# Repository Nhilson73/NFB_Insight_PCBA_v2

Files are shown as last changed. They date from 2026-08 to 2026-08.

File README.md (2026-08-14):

# NFB Insight PCBA v2

PCBA **shield/carrier** para **Nebula Fermentation Insight®**, diseñada alrededor del factor de forma inmutable del **Arduino UNO Q**. El repositorio `Nhilson73/nebula_qshield_pcb` es únicamente donante de ingeniería/trazabilidad; no gobierna placement, routing ni topología de producción V2.

## Fuente primaria UNO Q

Toda decisión dependiente del Arduino UNO Q se contrasta primero contra repositorios oficiales Arduino en GitHub (`github.com/Arduino`, especialmente `arduino/docs-content`), luego `docs.arduino.cc` y finalmente datasheets oficiales. La jerarquía y snapshots revisados viven en `docs/SOURCE_OF_TRUTH.md`.

## Frontera del producto / compliance

NFB Insight PCBA v2 es un **shield/carrier del UNO Q**, no un rediseño de su radio. No añade transmisores, antena, matching ni amplificación RF. El **EU Compliance Design Gate** vive en `docs/EU_COMPLIANCE_GATE.md` / `compliance/eu_compliance_contract.json` y cubre EMC, RoHS 3, REACH, WEEE, RED/CE del producto integrado.

## Mecánica y placement — PR #16 / #17 / ECO PR #22 / #24

- UNO Q rotado; origen global `(0,0)`; USB-C hacia `-Y`.
- Envolvente UNO Q / Z0: `53.34 × 68.58 mm`.
- Altura total PCB fija `68.58 mm`; crecimiento solo `+X`.
- `Y=0` = FIELD I/O EDGE; cables hacia `-Y`.
- Gradiente: Z0 UNO Q → Z1 sensores → Z2 digital → Z3 potencia → Z4 actuadores.
- **Ancho final de placement: `242.34 mm`.**
- Z0 `0.00→53.34 mm`.
- Z1 `53.34→108.84 mm` = `55.50 mm`.
- Z2 `108.84→163.34 mm` = `54.50 mm`.
- Z3 `163.34→198.34 mm` = `35.00 mm`.
- Z4 `198.34→242.34 mm` = `44.00 mm`.
- 119 footprints de producción + `J_UNOQ` = 120 footprints.
- 60 nets materializadas desde PR19D; `5V_HMI` es la net ECO añadida después de PR19C.
- PR17 cerró courtyard overlaps y fallos físicos de placement.
- PR22 aplicó el ECO acotado de placement alrededor del `TPSM33625` en Z3.
- PR24 acercó `TP_LOAD_A_POS/NEG` al HX711 en Z2 sin alterar el resto del placement.

## Z1 sensores

- pH/A0 y DO/A5: 0–3 V acondicionados, ESD + `1 kΩ / 100 nF`.
- ORP/A1: divisor `10 kΩ / 20 kΩ`, máximo 3.0 V.
- TEMP/A2-D16: DS18B20 `TEMP_1WIRE`.
- CO₂: Honeywell `MPRLS0030PA00002A`, I²C `0x28`; `CO2_ADC` retirado.
- A4/pad13 = `PUMP_CURRENT_ADC`.

## Z2 digital / bajo ruido

- I²C: MPR `0x28` + DFR1103 `0x66`.
- HX711 3.3 V / 10 SPS en D2/D3.
- HMI: **Nextion Intelligent `NX8048P050-011C-Y`**, 5.0 in capacitiva con enclosure, 800×480; D0/D1 mediante `TXU0202DCUR`.
- Accesorios HMI seleccionados: `SDExtender` + `Nextion BOX Speaker`; `Foca Max` queda como herramienta de programación/servicio.
- HMI+speaker reserva **5 V / 1.5 A**. PR19D cerró el ECO con `5V_HMI` dedicado externo (RECOM `R-78K5.0-2.0L` + fusible 2 A); display/audio ya no cargan `5V_RAIL`.
- Watchdog `TPS3823-30DBVR`, WDI=D4.
- `J_LOADCELL`: Phoenix Contact **1757268 / MSTBA 2,5/4-G-5,08**.

## Z3 potencia

Fuentes: `hardware/power_architecture_contract.json`, `hardware/power_production_netlist.json`, `hardware/power_netclasses.json` y `bom/insight_power_production_bom.csv`.

- 12 V protegido → VIN del UNO Q.
- `5V_RAIL` y `3V3_RAIL` son locales del shield; no se unen a J_UNOQ.5/J_UNOQ.4.
- Protección `SMBJ15A-TR + TPS259470ARPWR`.
- Split `12V_HOST_VIN / 12V_LOGIC / 12V_ACT`.
- `F_ACT=045401.5MR`.
- 5 V `TPSM33625RDNR`; 3.3 V `TLV75533PDBVR`.
- Potencia del chiller externa.

## Z4 actuadores

- Bomba `DRV8242HQRHLRQ1`, D5/D6, IPROPI → A4.
- Solenoide `TPS1HC120CQDYCRQ1`, D7, ILIM ~0.5 A.
- Chiller `AQY212EHAX` + `2N7002`, **dry contact SELV ≤48 V / NO MAINS**.
- D10=`ACT_FAULT_N`; D9 DNP/Reserva.

## Hierarchy EDA — PR #14 / #15

`kicad/NFB_Insight_PCBA_v2.kicad_sch` es el root Z0–Z4. PR #15 materializó las hojas desde JSON/BOM de forma determinista y eliminó completamente la deuda ERC del PR #14.

KiCad **10.0.5** sobre el hierarchy completo:

- **0 Errors**
- **0 Warnings**
- **0 violations**

Los JSON/BOM siguen siendo autoridad; las hojas generadas no deben editarse manualmente para alterar conectividad.

## Routing readiness — PR #18

Fuente: `hardware/routing_contract.json`; narrativa: `docs/FASE5_PR18_ROUTING_READINESS.md`.

PR #18 **no añadió cobre**. Su función fue congelar las reglas antes de rutear:

- exactamente **59/59 nets** cubiertas una sola vez por 11 clases;
- mínimos de potencia heredados de PR #10 no pueden debilitarse;
- `In1.Cu` = **GND continuo; signal routing prohibido**;
- `In2.Cu` = distribución de potencia, sin analógica sensible;
- pH/ORP/DO, load-cell/HX711 y `PUMP_CURRENT_ADC` forman dominio sensible;
- `12V_ACT`, `PUMP_OUT1/2` y `CO2_SOL_POS` forman dominio dirty;
- separación contractual sensitive↔dirty ≥ `1.00 mm` en recorridos paralelos;
- `12V_ACT` y retornos high-current no atraviesan Z1/Z2;
- contactos de chiller permanecen aislados, SELV ≤48 V y sin tie a GND;
- `SW`, `CO2_ADC`, `TEMP_ADC`, `HUM_ADC`, `CO2_PWM`, `CO2_FLOW_PWM` y `RS485_IRQ_RSVD` están prohibidas como nets de producción.

El `TPSM33625` es un módulo integrado y no expone una net SW externa. Su entrada/salida/feedback deben permanecer compactos en Z3.

## Tooling KiCad — PR #25

Las reglas operativas para agentes y automatización KiCad viven en `docs/KICAD_TOOLING_NOTES.md`, `docs/ROUTING_KNOWLEDGE_BASE.md` y `hardware/kicad_tooling_contract.json`.

Principios relevantes:

- `.kicad_pcb + .kicad_pro + .kicad_dru` se tratan como triplete canónico;
- KiCad 10.0.5 DRC es la autoridad física final;
- no se relajan clearances globales para hacer pasar routing;
- pads compuestos se modelan como geometría múltiple pero un endpoint lógico por `(ref,pin)`;
- placement se valida semánticamente, no por identidad textual/UUID del PCB;
- workflows finales de aceptación son `contents: read`.

## Routing incremental — divide y vencerás

El PR #19 monolítico fue usado como **laboratorio de routing** y se cerró sin merge. Demostró que mezclar señales locales, long-haul, potencia y GND en un solo PR aumenta la congestión y dificulta auditar la calidad geométrica.

La base de conocimiento vive en `docs/ROUTING_KNOWLEDGE_BASE.md` y la partición machine-readable en `hardware/routing_batches_contract.json`.

Las **60 nets vigentes** quedan divididas exhaustivamente y sin solapes. Los lotes PR19A/B/C conservan sus manifests históricos; PR19D introduce únicamente la net creada por el ECO HMI:

- **PR19A: 28** nets locales.
- **PR19B: 4** nets analógicas inter-zona: `PH_ADC`, `ORP_ADC`, `DO_ADC`, `PUMP_CURRENT_ADC`.
- **PR19C: 16** nets digital/control inter-zona.
- **PR19D: 1** net ECO local de potencia HMI: `5V_HMI`.
- **PR20A: 10** nets de potencia + salidas de actuadores.
- **PR20B: 1** net GND, tratada como plano `In1.Cu` + stitching; el probe experimental identificó 83 endpoints.

Total vigente: **28 + 4 + 16 + 1 + 10 + 1 = 60**.

Política de merge: **ALL_OR_NOTHING por lote**. No se mergea progreso parcial de un lote: todas sus nets deben estar conectadas, ninguna net futura puede ser tocada, no puede haber shorts/clearance/courtyard nuevos y placement/outline deben permanecer congelados.

La calidad de routing se evalúa también por longitud, segmentos, vías y cambios de dirección. Una ruta meandriforme no se acepta únicamente porque pase conectividad.

## PR19A — 28 nets locales / PR #28

El primer lote físico de producción queda materializado y persistido sobre el placement post-PR22/post-PR24.

Estado congelado del checkpoint:

- **28/28 nets PR19A con cobre.**
- **31/31 nets de lotes futuros sin cobre.**
- **523 segmentos.**
- **24 vías.**
- `In1.Cu`: **0 signal tracks**.
- copper zones: **0**.
- KiCad 10.0.5 DRC: **0 errors**.
- DRC warnings conocidos: **255**, exclusivamente deuda de serigrafía/texto:
  - `silk_edge_clearance`: 13;
  - `text_height`: 1;
  - `silk_overlap`: 173;
  - `silk_over_copper`: 68.
- unconnected restantes: **204**; ninguno pertenece a las 28 nets PR19A y corresponden a lotes futuros todavía no rutados.

La pasada de calidad redujo dos rutas excesivamente fragmentadas sin cambiar sus corredores DRC-clean:

- `5V_PGOOD`: **143 → 12 segmentos**.
- `WDT_MR_N`: **100 → 10 segmentos**.

El PCB de este checkpoint está persistido en `kicad/NFB_Insight_PCBA_v2.kicad_pcb`; el manifest de evidencia vive en `hardware/pr19a_local_routing_manifest.json` y el probe en `hardware/pr19a_local_probe.json`.

## PR19B — 4 nets analógicas long-haul / PR #30

PR #30 materializó el segundo lote de producción bajo política **ALL_OR_NOTHING**:

- `PH_ADC`
- `ORP_ADC`
- `DO_ADC`
- `PUMP_CURRENT_ADC`

Checkpoint congelado post-merge:

- **4/4 nets PR19B conectadas.**
- PR19A preservado íntegramente: **523 segmentos / 24 vías**.
- PR19B añadió **32 segmentos / 7 vías**.
- acumulado de producción: **555 segmentos / 31 vías**.
- **27 nets futuras sin cobre** al cierre de PR19B.
- `In1.Cu`: **0 signal tracks**.
- copper zones: **0**.
- KiCad 10.0.5 DRC: **0 errors**.
- warnings conocidos: **255**, sin deuda nueva de cobre.
- unconnected restantes: **192**.
- placement y outline congelados sin cambios.
- workflows finales de aceptación: **15/15 verdes**.

Los guardrails históricos fueron promovidos para reconocer de forma exacta `PRE_ROUTING → PR19A → PR19B` mediante contratos/manifests versionados, sin relajar DRC. Evidencia: `hardware/pr19b_analog_routing_manifest.json`; narrativa: `docs/FASE5_PR19B_ANALOG_ROUTING.md`.

## PR19C — 16 nets digital/control inter-zona / PR #31

PR #31 materializó el tercer lote de producción bajo política **ALL_OR_NOTHING**:

`ACT_FAULT_N`, `CHILLER_CTL`, `CO2_SOL_CTL`, `HMI_RX`, `HMI_TX`, `HX711_DOUT`, `HX711_SCK`, `I2C_SCL`, `I2C_SDA`, `LED_STATUS`, `MCU_NRST`, `MCU_WDI`, `PUMP_DIR`, `PUMP_PWM`, `TEMP_1WIRE`, `UNO_IOREF_3V3`.

Checkpoint congelado post-merge:

- **16/16 nets PR19C conectadas.**
- PR19A y PR19B preservados: **32/32 nets previas**.
- PR19C añadió **362 segmentos / 88 vías**.
- acumulado de producción: **917 segmentos / 119 vías**.
- **48/59 nets de producción ya ruteadas**.
- **11 nets PR20A/PR20B permanecen sin cobre**.
- `In1.Cu`: **0 signal tracks**.
- copper zones: **0**.
- KiCad 10.0.5 DRC: **0 errors**.
- warnings conocidos: **255**, exactamente la deuda histórica de serigrafía/texto.
- unconnected restantes: **154**.
- placement y outline congelados sin cambios.
- todas las nets PR19C cumplen el gate geométrico de **≤10 vías por net**.
- workflows finales de aceptación: **15/15 verdes**.

Durante el cierre se aplicaron dos correcciones geométricas controladas sin alterar conectividad ni reglas: `CO2_ILIM` se reperfiló **4→4 segmentos / 0→0 vías** para abrir el corredor de `ACT_FAULT_N`, y una vía `I2C_SDA` se desplazó localmente para cerrar el spacing `hole_to_hole` sin cambiar topología ni conteos.

Los guardrails históricos reconocen ahora de forma exacta `PRE_ROUTING → PR19A → PR19B → PR19C`. El manifest final es `hardware/pr19c_digital_routing_manifest.json` con status `DIGITAL_ROUTING_PR19C`; la narrativa vive en `docs/FASE5_PR19C_DIGITAL_ROUTING.md`.

## RF / enclosure

La fuente primaria Arduino revisada no publicó un antenna keepout numérico textual. NFB no inventa una distancia. Z0 permanece libre de footprints NFB y, durante routing, solo se permiten escapes mínimos hacia/desde `J_UNOQ`; la revisión final de cobre/enclosure/stacking/RF sigue siendo un gate de release.

## Estado actual

Placement y ECOs PR22/PR24 están congelados. PR18 congeló las reglas de routing y PR25 consolidó tooling KiCad. **PR28 cerró PR19A (28/28), PR30 cerró PR19B (4/4), PR31 cerró PR19C (16/16) y PR19D cerró el ECO HMI `5V_HMI` 1/1. El PCB vigente queda en 49/60 nets ruteadas, 924 segmentos, 121 vías, 0 zones, DRC físico 0 errores y 151 unconnected. PR20A conserva sus 10 nets históricas y queda como siguiente lote de cobre.**

**Siguiente checkpoint de producción: PR20A — routing de 10 nets de potencia + salidas de actuadores (`12V_IN_RAW`, `12V_PROTECTED`, `12V_HOST_VIN`, `12V_LOGIC`, `12V_ACT`, `5V_RAIL`, `3V3_RAIL`, `PUMP_OUT1`, `PUMP_OUT2`, `CO2_SOL_POS`). PR20B/GND permanece diferido hasta cerrar PR20A.**

## HMI power ECO — PR19D

La HMI Nextion `NX8048P050-011C-Y` + BOX Speaker usa alimentación externa dedicada `5V_HMI`: Littelfuse `0FHM0001ZXJ` + `0997002.WXN` 2 A → RECOM `R-78K5.0-2.0L` 5 V/2 A. La corriente de display/audio no atraviesa `5V_RAIL` de la PCBA. En la placa, `5V_HMI` solo alimenta `J_HMI.1`, `TXU0202 VCCB` y `C_HMI_B`. Nuevo lote de routing `PR19D` 1/1 antes de PR20A. Ver `docs/HMI_POWER_ECO_PR19D.md`.

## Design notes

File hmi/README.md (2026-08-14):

# HMI Nextion

HMI de producción seleccionada: **Nextion NX8048P050-011C-Y**.

Los proyectos de interfaz deben conservar dos artefactos trazables por release:

- fuente editable Nextion: `.HMI`;
- binario compilado/liberado: `.tft`.

Convención sugerida: `NFB_Insight_HMI_vMAJOR.MINOR.PATCH.HMI/.tft`.

Materializador canónico de la decisión de hardware/accesorios: `../tools/apply_hmi_nextion_decision_v2.py`.

El conjunto congelado incluye:

- HMI `NX8048P050-011C-Y`;
- `SDExtender`;
- `Nextion BOX Speaker`;
- `Foca Max` únicamente como herramienta de servicio/programación.

Las huellas mecánicas externas viven en `../kicad/lib/nfb_footprints.pretty/` y no se insertan en el PCB de producción. La integración eléctrica, BOM, fuentes oficiales y gates están en `../hardware/hmi_system_contract.json` y `../docs/HMI_NEXTION_NX8048P050.md`.

No colocar archivos generados sin versión ni backups del editor en este directorio.

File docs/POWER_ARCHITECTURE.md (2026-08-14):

# NFB Insight PCBA v2 — Arquitectura y Producción de Potencia

**Arquitectura:** PR #9 — Fase 3  
**Baseline discreto:** PR #10  
**Objeto:** shield/carrier del Arduino UNO Q  
**Entrada nominal:** 12 VDC  
**Fuentes de verdad:** `hardware/power_architecture_contract.json` + `hardware/power_production_netlist.json`  
**Fuente primaria UNO Q:** repositorios oficiales `arduino/*`, según `docs/SOURCE_OF_TRUTH.md`

## 1. Frontera eléctrica con UNO Q

La revisión del repositorio oficial `arduino/docs-content` confirma que UNO Q admite USB-C a 5 V, VIN 7–24 V y alimentación regulada de 5 V mediante JANALOG. NFB selecciona **12 V protegidos → VIN** como método base.

El shield genera sus propios `5V_RAIL` y `3V3_RAIL` y no los une a J_UNOQ.5/J_UNOQ.4. `IOREF` se usa solo como salida/referencia de alta impedancia para secuenciar el shield y nunca se retroalimenta.

## 2. Árbol de potencia de producción

```text
J_PWR_IN 12 V
   │
   ├── D_IN_TVS SMBJ15A-TR → GND
   ├── C_IN_HF 100 nF / 50 V
   │
   └── U_EFUSE TPS259470ARPWR
            │
            └── 12V_PROTECTED + C_IN_BULK 100 µF / 25 V
                   ├── NT_HOST  ──> 12V_HOST_VIN ──> J_UNOQ.8 VIN
                   ├── NT_LOGIC ──> 12V_LOGIC ──> TPSM33625 ──> 5V_RAIL
                   └── F_ACT 1.5 A Slo-Blo ──> 12V_ACT

UNO Q IOREF ──> EN TPSM33625
5V_PGOOD   ──> EN TLV75533
TLV75533   ──> 3V3_RAIL

Chiller: alimentación externa; señal de control únicamente.
```

## 3. Entrada y protección — TPS259470ARPWR

### 3.1 Red UVLO/OVLO

Se adopta el ladder de tres resistencias de la aplicación TI:

```text
12V_IN_RAW ─ R1 470k ─ EN/UVLO ─ R2 11k ─ OVLO ─ R3 47k ─ GND
```

Con referencia nominal de 1.2 V:

- `UVLO ≈ 1.2 × (470k + 11k + 47k) / (11k + 47k) = 10.924 V`;
- `OVLO ≈ 1.2 × (470k + 11k + 47k) / 47k = 13.481 V`.

Los valores nominales quedan próximos a la ventana de diseño 10.8–13.2 V; las tolerancias reales del IC y resistores se validarán en bring-up.

### 3.2 Corriente, dV/dt y timer

- `R_EFUSE_ILIM = 750 Ω / 1 %`.
- Relación típica de diseño: `3334 / 750 ≈ 4.445 A`; el contrato conserva `4.452 A typ` de referencia de datasheet.
- `C_EFUSE_DVDT = 3.3 nF`.
- `C_EFUSE_ITIMER = 2.2 nF`.
- `AUXOFF` y `FLT` quedan NC en Insight base.

El valor de 750 Ω conserva además el criterio publicado por TI para reconocimiento UL 2367 del dispositivo. La protección general no convierte por sí sola al producto final en certificado; el conjunto debe mantener su expediente y ensayos aplicables.

### 3.3 TVS y bulk

- `D_IN_TVS = SMBJ15A-TR`, unidireccional, 15 V, 600 W, SMB.
- `C_IN_HF = 100 nF / 50 V X7R` junto a la entrada.
- `C_IN_BULK = EEEFK1E101P`, 100 µF / 25 V, después del eFuse.

No se congela todavía un filtro LC serie adicional. Añadir inductancia sin medir impedancias, cableado y emisiones puede empeorar resonancias. La red adicional se decidirá con pre-scan de emisiones conducidas y surge.

## 4. Split estrella y rama de actuadores

El split de `12V_PROTECTED` se hace explícito mediante:

- `NT_HOST`: `12V_PROTECTED → 12V_HOST_VIN`;
- `NT_LOGIC`: `12V_PROTECTED → 12V_LOGIC`;
- `F_ACT`: `12V_PROTECTED → 12V_ACT`.

`F_ACT = Littelfuse 045401.5MR`, 1.5 A Slo-Blo Nano². El envelope de pico usado para arquitectura es 0.8 A bomba + 0.25 A solenoide = 1.05 A. La curva tiempo-corriente y el inrush real se validarán con cargas finales durante HIL.

Los retornos de `12V_ACT` deben regresar a la región de entrada/estrella sin atravesar Z1/Z2.

## 5. Buck 5 V — TPSM33625RDNR

Baseline discreto:

- `VIN = 12V_LOGIC`;
- `EN = UNO_IOREF_3V3` con `R_5V_EN_PD = 100 kΩ` a GND;
- `VOUT = 5V_RAIL`;
- `RT` unido a `VCC` → **1 MHz**;
- feedback: `R_5V_FBT = 40.2 kΩ`, `R_5V_FBB = 10 kΩ`;
- entrada: `4.7 µF / 50 V X7R + 100 nF / 50 V`;
- `VCC`: 1 µF;
- salida: `2 × 22 µF / 16 V X7R + 100 nF`;
- `PGOOD`: pull-up de 47 kΩ a `5V_RAIL`.

Los dos capacitores de 22 µF suman 44 µF nominales. **Antes de placement/fabricación se debe comprobar su DC-bias a 5 V** para garantizar al menos 25 µF efectivos combinados.

Los pines SW y BOOT del módulo no reciben componentes externos en este baseline; el cobre SW deberá quedar confinado a la isla recomendada por TI.

## 6. LDO 3.3 V — TLV75533PDBVR

Pinout contractual:

- pin 1 `IN = 5V_RAIL`;
- pin 2 `GND`;
- pin 3 `EN = 5V_PGOOD`;
- pin 4 `NC`;
- pin 5 `OUT = 3V3_RAIL`.

Capacitores:

- `C_3V3_IN = 1 µF / 25 V`;
- `C_3V3_OUT = 1 µF / 25 V`;
- `C_3V3_HF = 100 nF`.

## 7. Secuencia

1. 12 V llegan a `J_PWR_IN`.
2. TVS/eFuse generan `12V_PROTECTED`.
3. `12V_HOST_VIN` energiza al UNO Q por VIN.
4. El power tree del UNO Q levanta `IOREF`.
5. `IOREF` habilita el TPSM33625.
6. Al estabilizarse 5 V, `5V_PGOOD` habilita TLV75533.
7. Se habilita `3V3_RAIL` para sensores/lógica.

Bring-up debe probar, además, escenarios USB-C presente/ausente y fuente principal presente/ausente para demostrar ausencia de back-feed.

## 8. Screening térmico a 60 °C

Este análisis es **screening**, no validación final de PCB:

- Corriente equivalente del envelope total: `43.5 W / 12 V = 3.625 A`.
- TPS25947 con `RON typ = 28.3 mΩ`: pérdida estimada ≈ `0.372 W` a 3.625 A y ≈ `0.561 W` a 4.452 A.
- TPSM33625: usando 88 % como referencia conservadora para 7.5 W de salida, pérdida ≈ `1.02 W`; el valor real depende del punto de carga y layout.
- TLV75533 a 250 mA: `(5 - 3.3) × 0.25 = 0.425 W`; usando `RθJA ≈ 60.3 °C/W` de referencia, `Tj ≈ 85.6 °C` con 60 °C ambiente.

La termografía con PCB real, cobre final y enclosure sigue siendo obligatoria antes del RC.

## 9. Netclasses congeladas contractualmente

`hardware/power_netclasses.json` define mínimos iniciales:

| Clase | Nets | Ancho mínimo | Clearance mínimo |
|---|---|---:|---:|
| `PWR_INPUT_5A` | 12V_IN_RAW, 12V_PROTECTED | 2.0 mm | 0.50 mm |
| `PWR_12V_BRANCH` | HOST/LOGIC/ACT | 1.0 mm | 0.40 mm |
| `PWR_5V` | 5V_RAIL | 0.75 mm | 0.30 mm |
| `PWR_3V3` | 3V3_RAIL | 0.40 mm | 0.25 mm |
| `PWR_CONTROL` | FB/PGOOD/UVLO/etc. | 0.25 mm | 0.25 mm |

Son restricciones contractuales previas al routing; deberán aplicarse físicamente en KiCad y revalidarse con el stackup/cobre del fabricante.

## 10. Gates antes de placement

PR #10 **no autoriza placement ni routing**. Permanecen abiertos:

1. crear/auditar footprint `TPS259470A RPW-10` desde package drawing TI;
2. crear/auditar footprint `TPSM33625 RDN-11` desde package drawing TI;
3. validar DC-bias de `C_5V_OUT1/2`;
4. cerrar MPN exacto del capacitor dV/dt de 3.3 nF;
5. comprobar consumo/inrush de bomba, solenoide, HMI y sensores;
6. termografía y pre-compliance EMC del conjunto.

## 11. Fuentes primarias

### UNO Q

Snapshot oficial Arduino `arduino/docs-content` commit `196feda03787005572a059f030677b8a1de9bcd2`:

- `content/hardware/02.uno/boards/uno-q/datasheet/datasheet.md`;
- `content/hardware/02.uno/boards/uno-q/tutorials/03.power-specification/content.md`;
- `content/hardware/02.uno/carriers/uno-breakout-carrier/datasheet/datasheet.md`.

### Shield

- Texas Instruments: `TPS259470ARPWR`, `TPSM33625RDNR`, `TLV75533PDBVR`.
- Phoenix Contact: `1757242`.
- Littelfuse: `045401.5MR`.
- STMicroelectronics: `SMBJ15A-TR`.
- Panasonic: `EEEFK1E101P`.
- TDK/Murata: capacitores cerámicos seleccionados en la BOM.

La BOM final para fabricación deberá acompañarse de evidencia RoHS/REACH conforme al EU Compliance Gate.

## 12. Addendum PR19D — alimentación HMI dedicada

PR9/PR10 permanece como baseline histórico de la **PCBA principal**. La selección posterior de `NX8048P050-011C-Y` + BOX Speaker reveló que reservar 1.5 A sobre `5V_RAIL` consumiría todo el límite continuo de diseño de ese rail. PR19D resuelve el conflicto fuera de Z3, sin mover el TPSM33625 ni sus pasivos:

```text
12 V sistema — split externo upstream del eFuse NFB
  → Littelfuse 0FHM0001ZXJ
  → Littelfuse 0997002.WXN / 2 A
  → RECOM R-78K5.0-2.0L / 5 V, 2 A
  → 5V_HMI
```

La corriente de display/audio permanece en el arnés externo. `5V_HMI` entra a la PCBA únicamente por `J_HMI.1` para `TXU0202 VCCB` y `C_HMI_B`; `5V_RAIL` deja de alimentar la HMI. Ambos rails comparten GND de sistema porque el RECOM seleccionado es no aislado, pero **no pueden unirse entre sí**.

El presupuesto de salida HMI es 7.5 W. Como screening conservador a 90 % de eficiencia equivale a ~8.33 W de entrada; por margen de sistema se recomienda fuente certificada **12 V / 6 A (72 W)**. La rama HMI lleva protección 2 A propia.

Este addendum no altera el eFuse, buck 5 V, LDO 3.3 V, split estrella ni placement de la PCBA principal. El first article debe validar arranque/corriente, temperatura del convertidor, ausencia de nuisance-trip, mating y EMC. Fuente de verdad: `hardware/hmi_power_eco.json`.

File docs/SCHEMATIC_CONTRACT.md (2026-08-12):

# NFB Insight PCBA v2 — Contrato de Esquemático

**Estado:** baseline Z1 congelado por PR #6  
**Producto:** NFB Insight  
**Firmware de referencia:** `Nhilson73/Nebula_ArduinoAPPLab_UNOQ` @ `cf100b38df890f61aed472e934241e145425569b`  
**Fuente de verdad sensores:** `hardware/sensor_interface_contract.json`  
**Netlist Z1:** `hardware/z1_production_netlist.json`

## Principio

La V2 hereda conocimiento del Q-Shield, no su topología. Todo cambio eléctrico debe mantenerse coherente entre contrato de pines, contrato de sensores, netlist, BOM, KiCad y validadores.

## Contrato de pines UNO Q

| Pad | Pin | Net | Estado | Uso |
|---:|---|---|---|---|
| 1 | BOOT | NC | NC | No conectar |
| 2 | IOREF | NC | NC | No conectar |
| 3 | ~RESET | MCU_NRST | Activo | Supervisor |
| 4 | 3V3 | 3V3_RAIL | Activo | Lógica/sensores |
| 5 | 5V | 5V_RAIL | Activo | Módulos acondicionadores |
| 6 | GND | GND | Activo | Tierra |
| 7 | GND | GND | Activo | Tierra |
| 8 | VIN | 12V_RAIL | Revisar | Se resolverá en Fase 3 |
| 9 | A0 | PH_ADC | Activo | pH acondicionado |
| 10 | A1 | ORP_ADC | Activo | ORP escalado |
| 11 | A2/D16 | TEMP_1WIRE | Activo digital | DS18B20 |
| 12 | A3 | NC | DNP/Reserva | Humedad eliminada |
| 13 | A4 | NC | DNP/Reserva | `CO2_ADC` retirado en PR #6 |
| 14 | A5 | DO_ADC | Activo | DO acondicionado |
| 15 | D0 | HMI_RX | Activo | HMI |
| 16 | D1 | HMI_TX | Activo | HMI |
| 17 | D2 | HX711_DOUT | Activo | Celda de carga |
| 18 | D3 | HX711_SCK | Activo | Celda de carga |
| 19 | D4 | MCU_WDI | Activo | Watchdog |
| 20 | D5 | PUMP_PWM | Activo | Bomba |
| 21 | D6 | PUMP_DIR | Activo | Bomba |
| 22 | D7 | CO2_SOL_CTL | Activo | Solenoide CO₂ |
| 23 | D8 | CHILLER_CTL | Activo control | Energía fuera de PCBA |
| 24 | D9 | NC | DNP/Reserva | PWM proporcional fuera de Insight |
| 25 | D10 | RS485_IRQ_RSVD | Reserva | Signature futura |
| 26 | D11 | NC | NC | Reserva física |
| 27 | D12 | NC | NC | Reserva física |
| 28 | D13 | LED_STATUS | Activo | Estado |
| 29 | GND | GND | Activo | Tierra |
| 30 | AREF | NC | NC | No conectar |
| 31 | D20/SDA | I2C_SDA | Activo | Bus digital, incluye MPR `0x28` |
| 32 | D21/SCL | I2C_SCL | Activo | Bus digital, incluye MPR `0x28` |

## Z1 congelado

### pH
`J_PH → PESD3V3U1UL → 1 kΩ → PH_ADC`, con `100 nF` de PH_ADC a GND.

### ORP
`J_ORP → 10 kΩ → ORP_ADC`; desde ORP_ADC: `20 kΩ`, `PESD3V3U1UL` y `100 nF` a GND. El divisor convierte 4.5 V máximo en 3.0 V.

### Temperatura
`J_TEMP → TEMP_1WIRE`; `PESD3V3U1UL` a GND y pull-up onboard `4.7 kΩ` a 3.3 V.

### Presión CO₂
`U_CO2 = MPRLS0030PA00002A`, 0–30 psi absolute, I²C `0x28`, 3.3 V, `100 nF` de bypass. A4 no participa en presión.

### DO
`J_DO → PESD3V3U1UL → 1 kΩ → DO_ADC`, con `100 nF` de DO_ADC a GND.

## Conectores y mecánica de servicio

`J_PH`, `J_ORP`, `J_TEMP` y `J_DO` usan JST XH `S3B-XH-A(LF)(SN)` / footprint `JST_XH_S3B-XH-A_1x03_P2.50mm_Horizontal`. El placement deberá orientar la boca hacia `-Y`. El MPR es onboard y recibe presión mediante tubing a su puerto largo.

## Diferencias pendientes de firmware

El snapshot de firmware aún:
- lee temperatura con `analogRead(A2)`;
- lee presión CO₂ con `analogRead(A4)`.

Un PR de firmware deberá migrar a:
- DS18B20 / 1-Wire en A2-D16;
- Honeywell MPR I²C `0x28` en D20/D21.

## Reglas

1. `CO2_ADC` y `TEMP_ADC` están prohibidas como nets activas.
2. A3, A4 y D9 permanecen DNP/Reserva.
3. Ningún BNC, `MPX5700AP`, `SN6501`, `AMC1301` o `750315371` pertenece a la BOM base Z1.
4. Cambios de valores, MPN, footprint o nets requieren actualizar contrato, BOM, netlist, KiCad y CI en el mismo PR.
5. Placement/routing no pueden comenzar a reinterpretar silenciosamente este contrato.
6. ERC debe permanecer en cero antes de integrar a `main`.

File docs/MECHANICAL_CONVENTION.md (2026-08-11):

# NFB Insight PCBA v2 — Convención Mecánica

**Estado:** CONGELADO para el arranque de V2  
**Fuente donante:** `Nhilson73/nebula_qshield_pcb/docs/UNO_Q_FORM_FACTOR.md`

## 1. Sistema global de coordenadas

La nueva PCBA utiliza una convención cartesiana explícita y única:

- Origen global `(0,0)` = esquina inferior izquierda de la **envolvente rotada del UNO Q**.
- `+X` = dirección de expansión de la PCBA.
- `+Y` = dirección superior dentro del enclosure.
- `-Y` = dirección de salida de cables y servicio.
- El USB-C del Arduino UNO Q apunta hacia `-Y`.

La board no deberá crecer hacia X negativo ni Y negativo.

## 2. Envolvente inmutable del UNO Q

Envolvente oficial del UNO Q antes de rotarlo:

- Ancho: 68.58 mm
- Alto: 53.34 mm

Después de rotar el UNO Q para que el USB-C apunte hacia `-Y`, la envolvente inmutable queda:

- `X = 0.00 ... 53.34 mm`
- `Y = 0.00 ... 68.58 mm`

Por tanto:

- **La altura de la NFB Insight PCBA v2 queda congelada en 68.58 mm.**
- El ancho total de la board es variable y crecerá únicamente hacia `+X`, según lo determine el placement real.

## 3. Transformación de coordenadas desde la referencia donante

El repositorio donante expresa las coordenadas mecánicas del UNO Q en la orientación anterior. Para la orientación V2 se utilizará:

```text
X_v2 = 53.34 - Y_donor
Y_v2 = X_donor
```

### Centros de los agujeros de montaje rotados

| Agujero | X_v2 (mm) | Y_v2 (mm) |
|---|---:|---:|
| H1 | 50.80 | 13.97 |
| H2 | 45.72 | 66.04 |
| H3 | 17.78 | 66.04 |
| H4 | 2.54 | 15.24 |

Estas cuatro posiciones son inmutables mientras no cambie la especificación mecánica oficial del Arduino UNO Q.

## 4. Keepouts del UNO Q

El diseño V2 debe preservar acceso físico y clearance para todas las funciones del UNO Q, incluyendo como mínimo:

- USB-C
- botón de power
- JCTL
- SPI2 / JSPI
- QWIIC
- JMEDIA / JMISC cuando aplique
- volumen de acople de headers/shield
- tornillería, standoffs y elementos de montaje

Los keepouts son restricciones mecánicas obligatorias, no sugerencias de placement.

## 5. Borde de I/O de campo

Todo el borde inferior de la board en `Y = 0` queda designado como:

> **FIELD I/O EDGE**

Reglas:

1. Todos los conectores cableados de campo deberán ubicarse sobre el borde `Y=0` o inmediatamente adyacentes a él.
2. La dirección de conexión de los cables deberá apuntar hacia `-Y` siempre que la geometría del conector lo permita.
3. Los conectores de sensores deberán quedar directamente debajo, o tan cerca como sea práctico, de su circuito de front-end correspondiente.
4. No se rutearán señales de sensores de alta impedancia por largas distancias antes de su acondicionamiento.
5. Las cargas mecánicas de cables pesados o coaxiales deberán terminar preferiblemente en el panel del enclosure y no directamente en la PCBA.

## 6. Zonificación funcional hacia +X

El orden previsto de izquierda a derecha es:

```text
X = 0
│
├── Z0  UNO Q INMUTABLE
├── Z1  ANALÓGICO / FRONT-END DE SENSORES / AISLAMIENTO GALVÁNICO
├── Z2  DIGITAL / BAJO RUIDO / HX711 / I2C / HMI / RTC / GPS
├── Z3  GESTIÓN DE POTENCIA
└── Z4  ACTUADORES / POTENCIA RUIDOSA / SALIDAS DE CAMPO
                                      → +X
```

Los anchos de las zonas **no quedan congelados** en esta fase. Se determinarán a partir del placement real y de la manufacturabilidad.

## 7. Principios de placement

- Los circuitos analógicos sensibles permanecerán lo más cerca posible de su conector de campo.
- Los loops de conmutación del buck y los nodos de conmutación de actuadores se mantendrán alejados de los front-end de pH, ORP y DO.
- Se preservará un plano de referencia continuo bajo señales de bajo nivel.
- La congestión del autorouter nunca justificará violar la arquitectura de zonas.
- La ubicación del GPS deberá revisarse considerando antena, cobre y enclosure.
- Los test points deberán continuar accesibles para servicio después del ensamblaje del enclosure.

## 8. Criterio de liberación

Ningún routing se considerará con intención de producción hasta cumplir:

- coordenadas transformadas del UNO Q verificadas contra la referencia mecánica oficial;
- todos los keepouts representados en KiCad;
- orientación de los conectores del borde `Y=0` revisada en 3D;
- salida de cables del enclosure confirmada;
- límites de zonas revisados a partir del placement real y no de dibujos estimados.

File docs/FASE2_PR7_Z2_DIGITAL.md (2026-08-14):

# Fase 2 — PR #7: Z2 Digital / Bajo Ruido

## Estado

**Baseline eléctrico Z2 congelado**, con ECO posterior de potencia HMI PR19D. Este documento conserva la intención original de PR #7 y registra las decisiones posteriores que afectan Z2 sin reescribir su historia.

## 1. I²C global

El bus D20/D21 queda compartido por los dispositivos Insight:

- Honeywell MPRLS0030PA00002A, `0x28` — Z1.
- DFRobot DFR1103 GNSS+RTC, `0x66` — Z2.

`R_I2C_SDA` y `R_I2C_SCL` quedan poblados a **4.7 kΩ / 1 % hacia 3V3**. Los dos pull-ups locales de 10 kΩ reservados junto al MPR permanecen DNP.

No se incluye aislador I²C onboard en la línea base Insight. Las líneas que salen de la PCBA hacia el DFR1103 reciben protección ESD individual `PESD3V3U1UL,315` a GND.

## 2. GNSS + RTC — DFR1103 externo

Se reemplazan los módulos separados SAM-M8Q (`0x42`) y DS3231 (`0x68`) del diseño donante por un único **DFRobot DFR1103** externo.

La PCBA ofrece `J_GNSS_RTC`, JST XH de cuatro vías side-entry:

1. `I2C_SDA`
2. `I2C_SCL`
3. `GND`
4. `3V3_RAIL`

El arnés adapta XH-4 a Gravity 4P. PPS, INT y 32K del módulo no forman parte del baseline PR #7.

## 3. HX711 + celda de carga

`U_HX` se conserva onboard para Insight:

- alimentación analógica y digital desde `3V3_RAIL`;
- `RATE` a GND → 10 SPS;
- ganancia de canal A objetivo: 128;
- `DOUT` → D2 / `HX711_DOUT`;
- `PD_SCK` → D3 / `HX711_SCK`;
- canal B no usado;
- regulador interno no utilizado.

`J_LOADCELL` es un terminal Phoenix de 4 vías:

1. `3V3_RAIL` / E+
2. `GND` / E-
3. `LOAD_A_POS` / A+
4. `LOAD_A_NEG` / A-

## 4. HMI UART — Nextion + ECO de potencia PR19D

D0/D1 mantienen el contrato lógico:

- D0 = `HMI_RX`
- D1 = `HMI_TX`

La HMI seleccionada es **Nextion Intelligent Series `NX8048P050-011C-Y`**, 5.0" capacitiva con enclosure, 800×480. La interfaz lógica sigue usando **TI `TXU0202DCUR`**:

- UNO `HMI_TX` 3.3 V → `HMI_FIELD_RX` → RX de Nextion.
- TX de Nextion → `HMI_FIELD_TX` → UNO `HMI_RX` 3.3 V.

`J_HMI` conserva `S4B-XH-A(LF)(SN)` y su footprint side-entry; no se movieron pads para el ECO. El mating del arnés Nextion `XH2.54 4P` debe verificarse en first article.

### Alimentación final

El BOX Speaker añade 0.5 A al requisito de 1 A del display. Para evitar consumir todo el presupuesto histórico de `5V_RAIL`, PR19D cierra el ECO con un rail externo dedicado:

`12V sistema → fuse 2 A → RECOM R-78K5.0-2.0L → 5V_HMI`

En la PCBA:

1. `J_HMI.1 = 5V_HMI`
2. `U_HMI_LVL.7 / VCCB = 5V_HMI`
3. `C_HMI_B.1 = 5V_HMI`
4. `5V_HMI` **no** puede unirse a `5V_RAIL` ni a `J_UNOQ.5`.

La corriente de pantalla/audio permanece en el subensamble externo. La PCBA solo toma de `5V_HMI` la corriente de soporte del lado B del TXU0202.

PR19D cerró `5V_HMI` 1/1 con DRC=0, sin modificar placement, outline ni el cobre UART previo. Fuente de verdad: `hardware/hmi_system_contract.json`, `hardware/hmi_power_eco.json` y `docs/HMI_POWER_ECO_PR19D.md`.

## 5. Watchdog / supervisión

Se congela **TPS3823-30DBVR**:

- `RESET` → `MCU_NRST` / pad 3.
- `WDI` ← D4 / `MCU_WDI`.
- `MR_n` con pull-up de 10 kΩ.
- VDD = 3V3.
- timeout nominal: 1.6 s.
- firmware alimenta WDI cada 400 ms.

## 6. LED de estado

No se añade un LED externo. D13 / `LED_STATUS` conserva el LED integrado del UNO Q y se mantiene `TP_LED_STATUS`.

## 7. Test points de bring-up

Se congelan:

- `TP_3V3`, `TP_5V`, `TP_GND`
- `TP_I2C_SDA`, `TP_I2C_SCL`
- `TP_HX_DOUT`, `TP_HX_SCK`
- `TP_LOAD_A_POS`, `TP_LOAD_A_NEG`
- `TP_HMI_TX`, `TP_HMI_RX`
- `TP_WDI`, `TP_NRST`, `TP_WDT_MR`
- `TP_LED_STATUS`

## 8. Bloques expresamente excluidos de Insight Z2

No forman parte del baseline:

- MAX3485 / RS485
- SC16IS740
- SN74LVC1G04 del puente RS485
- ISO1541
- SAM-M8Q separado
- DS3231 onboard/separado
- Cell Density / Signature

D10 permanece solo como reserva contractual para una futura expansión deliberada.

## 9. Seguimiento de firmware

1. DFR1103 `0x66` sustituye GPS `0x42` + RTC `0x68`.
2. HX711 permanece sobre D2/D3.
3. watchdog permanece D4 con feed de 400 ms.
4. HMI UART permanece sobre TXU0202; la alimentación de campo es `5V_HMI` desde PR19D.

## 10. Gates vigentes

- contrato UNO Q + Z1 + Z2;
- referencias BOM = referencias netlist Z2;
- HX711 y DFR1103 congelados;
- TXU0202 preservado;
- `J_HMI.1/U_HMI_LVL.7/C_HMI_B.1 = 5V_HMI`;
- ausencia de puente `5V_HMI ↔ 5V_RAIL`;
- watchdog TPS3823-30;
- ERC del root = 0;
- DRC físico = 0;
- placement/outline congelados.

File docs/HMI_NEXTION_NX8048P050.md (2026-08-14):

# Decisión HMI — Nextion NX8048P050-011C-Y

## Estado

**SELECCIONADO para NFB Insight:** Nextion Intelligent Series 5.0" capacitiva con enclosure, MPN `NX8048P050-011C-Y`, SKU `6920075776553`.

Esta pantalla es un **ensamble externo**, no un footprint poblado sobre la PCBA. La shield mantiene `J_HMI` como interfaz de cable y el repositorio incorpora huellas mecánicas externas para la HMI y sus accesorios, utilizables en integración de enclosure/servicio sin contaminar BOM o pick-and-place de la PCBA.

**Actualización PR19D:** el ECO de potencia queda cerrado en diseño mediante una rama externa dedicada `5V_HMI`. La pantalla y el BOX Speaker ya no consumen desde `5V_RAIL` de la PCBA principal.

## Pantalla congelada

- MPN: `NX8048P050-011C-Y`.
- 5.0", 800×480, capacitiva.
- Intelligent Series, MCU 200 MHz, Flash 128 MB, SRAM 512 KB, EEPROM 1024 B.
- RTC CR1220; 8 GPIO; audio/video soportados.
- alimentación oficial: **5 V / 1 A**.
- USART: **XH2.54 4P**.
- operación: -20…70 °C; almacenamiento: -30…85 °C.
- envelope frontal oficial: **160.04 × 107.07 mm**; profundidad máxima **21.2 mm**.

Fuentes oficiales: https://itead.cc/product/5-0-nextion-intelligent-series-hmi-touch-display-with-enclosure/ y https://nextion.tech/datasheets/NX8048P050-011C-Y/; plano mecánico: https://cdn.nextion.tech/wp-content/uploads/2020/12/NX8048P050-011X-Y-Dimension.pdf.

## Interfaz con NFB PCBA

`J_HMI` permanece `S4B-XH-A(LF)(SN)` con footprint KiCad `Connector_JST:JST_XH_S4B-XH-A_1x04_P2.50mm_Horizontal`, side-entry hacia `-Y`.

La razón de **no mover pads** es deliberada: PR19C cerró el routing UART y PR19D solo reasigna eléctricamente el pin de potencia. ITEAD publica la interfaz del display como `XH2.54 4P` pero no publica en la ficha consultada un MPN JST exacto. Por tanto:

1. no se inventa una equivalencia 2.50 ↔ 2.54;
2. se conserva la geometría de producción del board-side connector;
3. el arnés final debe pasar **mating test de first article** antes de release;
4. cualquier cambio posterior de `J_HMI` será un ECO de footprint/routing explícito.

Mapping lógico: `HMI_TX` del UNO → TXU0202 → `HMI_FIELD_RX` → RX de Nextion; TX de Nextion → `HMI_FIELD_TX` → TXU0202 → `HMI_RX` del UNO. Campo protegido con `PESD5V0U1UL,315`.

Desde PR19D, `J_HMI.1 = 5V_HMI`; `5V_HMI` también alimenta `U_HMI_LVL.7` (VCCB) y `C_HMI_B.1`. No existe puente permitido entre `5V_HMI` y `5V_RAIL`.

## Accesorios seleccionados

### Nextion Micro SD Card Extender

- modelo `SDExtender`;
- 17.1 × 41.48 × 2.5 mm; 7 g;
- FAT32 microSD; compatible con todas las series Nextion;
- ensamble externo, no poblado en PCBA;
- footprint mecánico: `NFB:Nextion_SDExtender_External`;
- fuente: https://itead.cc/product/nextion-micro-sd-card-extender/.

### Nextion BOX Speaker

- 31 × 28 × 14.8 mm; 21.2 g;
- 1.5 W, 100 Hz–3 kHz;
- conector hembra 2P pitch 1.25 mm `1.25T-2-2A`; cable 250 mm;
- ITEAD exige **+0.5 A** sobre la recomendación de alimentación del display;
- reserva de diseño para display + speaker: **5 V / 1.5 A**;
- footprint mecánico: `NFB:Nextion_BOX_Speaker_External`;
- verificar acceso/montaje del audio con la variante `-Y` durante first article;
- fuente: https://itead.cc/product/nextion-box-speaker/.

### Nextion Foca Max

`Foca Max` queda como **herramienta de programación/bring-up, no instalada en el producto**:

- CP2102; TTL 3.3 V; hasta 2 Mbps;
- DC externo 8–26 V; salida 5–5.5 V, 2 A máx.;
- PCB 50 × 50 × 1.6 mm; volumen 50 × 50 × 12 mm;
- incluye USB wire y XH2.54 4P wire;
- footprint de referencia de servicio: `NFB:Nextion_Foca_Max_Service`;
- para pantallas >4.3" ITEAD recomienda alimentación DC externa 8–26 V;
- fuente: https://itead.cc/product/nextion-foca-max-5v2a-output-usb-to-ttl-serial-converter-board/.

## Footprints mecánicos congelados

Las huellas siguientes son **referencias mecánicas externas, sin pads**, y están marcadas para quedar excluidas de BOM/position files de la PCBA:

- `NFB:Nextion_NX8048P050_011C_Y_Enclosure` — 160.04 × 107.07 mm, profundidad máxima documentada 21.2 mm.
- `NFB:Nextion_SDExtender_External` — 17.1 × 41.48 mm, espesor 2.5 mm.
- `NFB:Nextion_BOX_Speaker_External` — 31 × 28 mm, altura 14.8 mm.
- `NFB:Nextion_Foca_Max_Service` — 50 × 50 mm, altura total 12 mm; servicio solamente.
- `NFB:RECOM_R78K5_0_2_0L_External` — referencia mecánica del convertidor dedicado HMI.

No se insertan estas huellas externas dentro de `NFB_Insight_PCBA_v2.kicad_pcb`.

## ECO de potencia PR19D — cerrado en diseño

El problema detectado en PR #32 era que `5V_RAIL` tenía un límite continuo de diseño de 1.5 A y HMI + speaker ya reservaban esos mismos 1.5 A, sin dejar margen a sensores ni al LDO de 3.3 V.

PR19D resuelve el conflicto sin mover placement de Z3 y sin usar capacidad ficticia del rail principal:

```text
12V sistema (split externo, upstream del eFuse de la PCBA)
   → Littelfuse 0FHM0001ZXJ
   → Littelfuse 0997002.WXN / 2 A
   → RECOM R-78K5.0-2.0L / 5 V, 2 A
   → 5V_HMI
      ├─ Nextion NX8048P050-011C-Y
      ├─ Nextion BOX Speaker
      └─ J_HMI.1 → TXU0202 VCCB + C_HMI_B
```

Consecuencias:

- display/audio no atraviesan la NFB PCBA v2;
- `5V_RAIL` queda para pH, ORP, DO y la cadena 3V3;
- `5V_HMI` es una net distinta y no puede unirse a `5V_RAIL`;
- el convertidor dedicado tiene 2.0 A nominales frente a 1.5 A reservados, es decir, **0.5 A de headroom nominal**;
- se recomienda fuente de sistema 12 V / 6 A para recuperar margen global.

PR19D introdujo `5V_HMI` como la net #60 y la ruteó como lote ALL_OR_NOTHING 1/1: **7 segmentos + 2 vías**, acumulado **924 segmentos / 121 vías**, `In1.Cu` sin señales, zones=0, DRC=0. El escape inmediato de `U_HMI_LVL.7` usa 0.20 mm por ≤1.20 mm debido al pitch VSSOP; el clearance permanece ≥0.20 mm y la distribución retorna a 0.40 mm.

El cierre de diseño no sustituye el first article: deben medirse arranque/corriente, temperatura del RECOM dentro del enclosure, comportamiento del fusible de 2 A, mating del arnés y EMC del cable final.

## Firmware y mantenimiento

- Transporte de producción: UART D0/D1 a través de `TXU0202DCUR`.
- Versionar fuente Nextion `.HMI` y binario liberado `.tft`.
- Actualización de campo/lab: microSD mediante `SDExtender`.
- Programación/diagnóstico de banco: `Foca Max`.

## Archivos fuente de verdad

- `hardware/hmi_system_contract.json`
- `hardware/hmi_power_eco.json`
- `hardware/pr19d_hmi_power_routing_manifest.json`
- `bom/insight_hmi_system_bom.csv`
- `docs/HMI_POWER_ECO_PR19D.md`
- `hardware/z2_digital_contract.json`
- `hardware/z2_production_netlist.json`
- `hardware/power_architecture_contract.json`
- `hardware/routing_contract.json`
- `hardware/routing_batches_contract.json`
- `kicad/lib/nfb_footprints.pretty/Nextion_NX8048P050_011C_Y_Enclosure.kicad_mod`
- `kicad/lib/nfb_footprints.pretty/RECOM_R78K5_0_2_0L_External.kicad_mod`

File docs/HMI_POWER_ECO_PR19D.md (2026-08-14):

# ECO de potencia HMI — PR19D / 5V_HMI

## Decisión

La Nextion `NX8048P050-011C-Y` y el `Nextion BOX Speaker` dejan de consumir desde `5V_RAIL` de la PCBA principal. El sistema adopta una rama externa dedicada, próxima a la HMI:

`12V sistema → 0FHM0001ZXJ + 0997002.WXN (2 A) → RECOM R-78K5.0-2.0L → 5V_HMI`

`5V_HMI` alimenta la pantalla y el speaker en el arnés externo. Ese mismo rail vuelve a `J_HMI.1` únicamente para `U_HMI_LVL.VCCB` y `C_HMI_B`; por ello la corriente de 1.5 A de display/audio **no atraviesa la NFB PCBA v2**.

## Componentes congelados

- RECOM `R-78K5.0-2.0L`: 5 V / 2 A / 10 W; Vin 6.5–36 V; no aislado; versión L horizontal de bajo perfil.
- Littelfuse holder `0FHM0001ZXJ`: MINI inline, 58 V máx., 14 AWG, IP67.
- Littelfuse fuse `0997002.WXN`: MINI 58 VDC / 2 A.

## Impacto EDA

- Nuevo net de producción: `5V_HMI` (59 → 60 nets).
- Nuevo lote `PR19D`: 1/1 net local en Z2.
- `J_HMI.1`, `U_HMI_LVL.7` y `C_HMI_B.1` migran de `5V_RAIL` a `5V_HMI`.
- `5V_RAIL` no tenía cobre en PR19C, por lo que el ECO no retira routing previo.
- HMI UART (`HMI_FIELD_RX/TX`, `HMI_RX/TX`) queda congelado.
- Placement, outline e In1.Cu no cambian.

## Potencia de sistema

La rama HMI reserva 7.5 W de salida. Como cribado conservador a 90 % de eficiencia equivale a ~8.33 W de entrada. Se recomienda 12 V / 6 A (72 W) para recuperar margen de sistema; la rama HMI queda protegida de forma independiente antes del convertidor.

## Release gates

El ECO eléctrico se considera cerrado en diseño cuando PR19D sea DRC=0. El producto aún requiere first article: corriente/arranque, temperatura del RECOM dentro del enclosure, no nuisance-trip del fusible 2 A, mating del arnés XH y EMC del cable final.

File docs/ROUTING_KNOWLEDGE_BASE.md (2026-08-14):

# Base de conocimiento de routing — NFB Insight PCBA v2

## Propósito

Este documento conserva el conocimiento de ingeniería aprendido durante la transición de placement a routing de producción. Su objetivo es evitar que decisiones críticas queden dispersas entre conversaciones, commits experimentales o logs de CI.

La regla de trabajo desde Fase 5 es **divide y vencerás**: cada lote de cobre debe ser pequeño, completo, reproducible, auditable y mergeable de forma independiente.

## Autoridad

La jerarquía de autoridad para routing es:

1. `hardware/routing_contract.json` — reglas eléctricas, netclasses, capas, anchos y clearances congelados en PR18.
2. `hardware/routing_batches_contract.json` — partición vigente de 60 nets; PR19D añadió `5V_HMI` después de PR19C sin reescribir manifests históricos.
3. `hardware/placement_manifest.json` — placement PR17 + cadena ECO vigente.
4. JSON/BOM de Z1/Z2/Z3/Z4 — conectividad y footprints de producción.
5. `kicad/NFB_Insight_PCBA_v2.kicad_dru` — reglas custom efectivas de KiCad.
6. KiCad 10.0.5 + DRC — autoridad física final para cobre.
7. `docs/KICAD_TOOLING_NOTES.md` — reglas técnicas de tooling.
8. Este documento — narrativa, rationale y lecciones aprendidas.

Ningún router, script u optimización puede debilitar los contratos anteriores para obtener un resultado “verde”.

## Geometría congelada

- Board: `242.34 × 68.58 mm`.
- Altura inmutable: `68.58 mm`.
- Crecimiento solo `+X`.
- Z0: `0.00 → 53.34 mm`.
- Z1: `53.34 → 108.84 mm`.
- Z2: `108.84 → 163.34 mm`.
- Z3: `163.34 → 198.34 mm`.
- Z4: `198.34 → 242.34 mm`.
- `Y=0` = FIELD I/O EDGE.
- Cables hacia `-Y`.
- Placement global PR17 permanece congelado; solo se permiten ECOs locales contractuales y mergeados antes de reiniciar routing.

## Política de capas

- `F.Cu`: señales críticas/locales, front-end analógico y loops compactos.
- `In1.Cu`: referencia GND continua; **sin signal routing**.
- `In2.Cu`: distribución de potencia y troncales de baja impedancia; sin analógica sensible.
- `B.Cu`: señales low-speed / control / telemetría long-haul cuando sea necesario.

## Partición vigente de las 60 nets

La partición es exhaustiva y mutuamente excluyente:

### PR19A — 28 nets locales

`FIELD_ANALOG_LOCAL`:
- `PH_FIELD_SIG`
- `ORP_FIELD_SIG`
- `DO_FIELD_SIG`

`CONTROL_SENSITIVE` locales:
- `5V_VCC`
- `5V_FB`
- `5V_PGOOD`
- `EFUSE_ILM`
- `EFUSE_ITIMER`
- `EFUSE_DVDT`
- `EFUSE_EN_UVLO`
- `EFUSE_OVLO`
- `CO2_ILIM`
- `PUMP_SR_CFG`

`ANALOG_SENSITIVE` locales / quiet:
- `HX_VBG`
- `LOAD_A_NEG`
- `LOAD_A_POS`

`CHILLER_DRY_CONTACT`:
- `CHILLER_CONTACT_A`
- `CHILLER_CONTACT_B`

`DIGITAL_LOW_SPEED` locales:
- `CO2_OPENLOAD_N`
- `CO2_EN_DRV`
- `PUMP_DIR_DRV`
- `PUMP_PWM_DRV`
- `CHILLER_GATE`
- `CHILLER_LED_A`
- `CHILLER_LED_K`
- `HMI_FIELD_RX`
- `HMI_FIELD_TX`
- `WDT_MR_N`

**Gate de merge PR19A:** 28/28 conectadas; 0 nets fuera del lote tocadas; 0 shorts; 0 errores nuevos de clearance/courtyard; placement/outline fuera de scope sin cambios; `In1.Cu` sin signal tracks.

### PR19B — 4 nets analógicas inter-zona

- `PH_ADC`
- `ORP_ADC`
- `DO_ADC`
- `PUMP_CURRENT_ADC`

Estas cuatro redes se revisan como dominio sensible. `PUMP_CURRENT_ADC` debe cruzar Z4→Z0 por el corredor más silencioso disponible y evitar los loops de switching/power-entry de Z3. La revisión visual de retorno contra el futuro plano GND es obligatoria antes de merge.

### PR19C — 16 nets digital/control inter-zona

- `ACT_FAULT_N`
- `CHILLER_CTL`
- `CO2_SOL_CTL`
- `HMI_RX`
- `HMI_TX`
- `HX711_DOUT`
- `HX711_SCK`
- `I2C_SCL`
- `I2C_SDA`
- `LED_STATUS`
- `MCU_NRST`
- `MCU_WDI`
- `PUMP_DIR`
- `PUMP_PWM`
- `TEMP_1WIRE`
- `UNO_IOREF_3V3`

B.Cu es el corredor preferente para long-haul low-speed; F.Cu se preserva para escapes locales, analógica y loops compactos.

### PR19D — 1 net ECO de potencia HMI

- `5V_HMI`

PR19D fue insertado después de PR19C para cerrar el ECO abierto por la selección de Nextion + BOX Speaker. `5V_HMI` nace en un subensamble externo 5 V / 2 A y entra a Z2 por `J_HMI.1`; en la PCBA solo alimenta `U_HMI_LVL.7` y `C_HMI_B.1`. No existe net-tie ni puente a `5V_RAIL`.

Routing cerrado: 7 segmentos + 2 vías; acumulado 924/121; DRC=0; `In1.Cu` sin señales; zones=0. El escape de `U_HMI_LVL.7` usa neck-down 0.20 mm por ≤1.20 mm únicamente para liberar el VSSOP, conservando clearance ≥0.20 mm y retornando a 0.40 mm.

**Gate PR19D:** `5V_HMI` 1/1 conectada, UART HMI previa intacta, placement/outline congelados, ninguna net PR20A/PR20B adelantada.

### PR20A — 10 nets de potencia + actuadores

Potencia:
- `12V_IN_RAW`
- `12V_PROTECTED`
- `12V_HOST_VIN`
- `12V_LOGIC`
- `12V_ACT`
- `5V_RAIL`
- `3V3_RAIL`

Salidas de actuadores:
- `PUMP_OUT1`
- `PUMP_OUT2`
- `CO2_SOL_POS`

Este lote usa F.Cu/In2.Cu según `routing_contract.json`; debe preservar la estrella Z3/Z4 y evitar retornos de alta corriente por Z1/Z2.

### PR20B — GND

- `GND`

Aunque es una sola net, el probe experimental identificó **83 endpoints**. Se trata como lote independiente porque define el plano continuo de `In1.Cu`, stitching y la calidad de los retornos analógicos/digitales/potencia.

## Lecciones del PR #19 experimental

PR #19 fue cerrado **sin merge** y su rama se conserva como laboratorio. Su valor es de conocimiento, no de cobre de producción.

Hallazgos principales:

1. Intentar resolver señales locales, long-haul, potencia y GND en un mismo PR genera demasiadas variables simultáneas.
2. El router experimental llegó a cerrar las 28 nets locales antes de entrar en congestión inter-zona; esa frontera es natural y reproducible.
3. El TPSM33625 y TPS259470A requieren prioridad de escape local por pitch fino; no se debe relajar el clearance global para “hacerlos pasar”.
4. El TPS1HC120 DYC0008A mostró garganta geométrica en `CO2_OPENLOAD_N` y `CO2_EN_DRV`; los escapes cortos deben tratarse como geometría local y siempre quedar bajo DRC KiCad.
5. Los primeros long-haul llegaron a producir cientos de segmentos por net. **Conectar no es suficiente**: calidad geométrica, número de giros, número de vías y claridad del corredor son criterios de aceptación.
6. `In1.Cu` no se usa como vía de escape de routing; queda reservado al plano GND.
7. Los rails multipunto (`3V3_RAIL` y `5V_RAIL`) no deben forzarse como pistas improvisadas alrededor de encapsulados finos; pertenecen al lote de potencia.

## Lecciones PR21–PR24: routing como detector de placement

Los PR21 y PR23 fueron cerrados sin merge porque el routing reveló problemas locales de placement que era mejor corregir antes de persistir cobre.

### PR22 — TPSM33625

Trigger: `5V_FB` y `5V_VCC` podían rutearse individualmente pero se bloqueaban mutuamente con el packing geométrico original.

Corrección: ECO mínimo de 5 pasivos alrededor de `U_5V`, manteniendo `U_5V` fijo. Resultado: DRC físico 0.

Regla preventiva: componentes de bypass, feedback y programación deben formar **micro-islas por función eléctrica**, no solo quedar “dentro de Z3”.

### PR23/PR24 — HX711 load-cell

Trigger: `LOAD_A_NEG` llegó a cerrar con ~198 segmentos, ~97.8 mm y 4 vías, mientras `LOAD_A_POS` se bloqueaba; ambos TP estaban en la banda superior lejos de `U_HX`.

Corrección: PR24 movió únicamente `TP_LOAD_A_POS` y `TP_LOAD_A_NEG` junto al HX711. Resultado: 2 refs movidas / 117 intactas, courtyard 0, DRC físico 0 y menor deuda de silk.

Regla preventiva: para entradas diferenciales de muy bajo nivel, el camino principal `J_LOADCELL → U_HX` es la topología prioritaria; los testpoints deben ser ramas secundarias cortas.

## Lecciones de tooling KiCad transferidas y verificadas

Detalle completo: `docs/KICAD_TOOLING_NOTES.md`.

Reglas que afectan directamente PR19A:

1. **Sandbox DRC = triplete de basename.** Una copia temporal del `.kicad_pcb` debe tener `.kicad_pro` y `.kicad_dru` homónimos al lado.
2. **`.kicad_pro` no define por sí solo el mínimo legal.** Las reglas custom de `.kicad_dru` pueden imponer límites/overrides distintos.
3. **Courtyard real por layer.** `footprint.GetBoundingBox()` no sustituye `F.Courtyard/B.Courtyard`.
4. **Pad-shapes duplicados se colapsan por `ref.pin` para conectividad**, pero siguen siendo obstáculos geométricos.
5. **Margen positivo en clearance propio.** Nunca hacer un planner ligeramente permisivo esperando que DRC “perdone”.
6. **PCB regenerado se compara semánticamente**, porque `pcbnew` puede generar UUIDs nuevos.
7. **CI final read-only.** No dejar auto-commits recurrentes sobre un artefacto no byte-estable.
8. **Gates históricos composicionales.** Cada ECO valida su delta y después reproduce la cadena vigente completa.
9. **`unconnected_item` no implica automáticamente una pista.** Con zones futuras, distinguir endpoints reales de islas/artefactos `Zone↔Zone`.

## Topología multipunto y endpoints lógicos

No imponer MST geométrico ciegamente.

- `5V_VCC`: bypass y strap RT→VCC tienen roles distintos; el árbol debe reflejar la función eléctrica.
- eFuse: ITIMER/UVLO/OVLO/ILM/DVDT se priorizan por confinamiento y conectividad del divisor/programación.
- footprints compuestos: varios pad-shapes con mismo número físico son un solo endpoint eléctrico.
- `LOAD_A_POS/NEG`: par principal acoplado; TP como stubs cortos.

## Micro-rutas y neckdown

Si una rejilla no representa un corredor que físicamente sí existe:

1. medir el corredor exacto;
2. usar waypoint/micro-ruta solo para ese caso;
3. mantener reglas globales intactas;
4. limitar cualquier neckdown por net/región;
5. DRC obligatorio.

No bajar resolución o clearance global para resolver una sola garganta.

## Criterio de merge por lote

Un lote solo puede mergearse si cumple simultáneamente:

- 100% de las nets declaradas en ese lote conectadas.
- 0 nets de lotes futuros ruteadas accidentalmente.
- 0 shorts.
- 0 errores nuevos de clearance físico.
- 0 courtyard collisions nuevas.
- placement semánticamente equivalente fuera de ECO aprobado.
- outline y dimensiones congelados.
- `In1.Cu` sin signal tracks hasta PR20B.
- cualquier warning/deuda restante está tipificado, contado y documentado; nunca se usa una exclusión genérica para ocultar violaciones de cobre.
- revisión visual de la topología del lote antes del merge.

No se mergean “17 de 28 porque funcionan”. Se mergea **28/28 o 0/28**.

## Calidad geométrica

Además de DRC, cada lote debe registrar:

- longitud aproximada por net;
- cantidad de segmentos;
- cantidad de vías;
- capa(s) utilizadas;
- número de cambios de dirección;
- desviación respecto al corredor previsto;
- proximidad de nets sensibles vs. dirty nets.

Los umbrales concretos pueden evolucionar, pero la tendencia debe favorecer rutas simples y auditables. Una ruta con cientos de pequeños segmentos no se acepta solo porque sea eléctricamente conectada.

## Regla de aprendizaje

Cada problema físico relevante descubierto durante routing debe incorporarse aquí con:

- síntoma;
- causa raíz;
- corrección aplicada;
- regla preventiva para futuros lotes;
- referencia al PR/commit que la materializó.

De esta forma el repositorio conserva no solo el resultado final, sino también el conocimiento de ingeniería que permitió llegar a él.

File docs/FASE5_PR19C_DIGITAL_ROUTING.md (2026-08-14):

# Fase 5 — PR19C: routing digital/control inter-zona

## Propósito

PR19C cierra el tercer lote incremental de routing de NFB Insight PCBA v2 bajo la política **ALL_OR_NOTHING** definida en `hardware/routing_batches_contract.json`.

El lote contiene exactamente 16 nets digital/control inter-zona:

- `ACT_FAULT_N`
- `CHILLER_CTL`
- `CO2_SOL_CTL`
- `HMI_RX`
- `HMI_TX`
- `HX711_DOUT`
- `HX711_SCK`
- `I2C_SCL`
- `I2C_SDA`
- `LED_STATUS`
- `MCU_NRST`
- `MCU_WDI`
- `PUMP_DIR`
- `PUMP_PWM`
- `TEMP_1WIRE`
- `UNO_IOREF_3V3`

PR20A y PR20B quedan expresamente fuera de alcance.

## Baseline de entrada

PR19C parte del checkpoint PR19B mergeado en PR #30:

- PR19A: 28/28 nets locales.
- PR19B: 4/4 nets analógicas long-haul.
- PCB acumulado: **555 segmentos / 31 vías**.
- DRC KiCad 10.0.5: **0 errores**.
- warnings conocidos: **255**, todos de serigrafía/texto.
- unconnected: **192**.
- `In1.Cu`: 0 signal tracks.
- copper zones: 0.
- 27 nets futuras sin cobre.

Antes de materializar PR19C se ejecutó un probe read-only para congelar endpoints, zonas y ocupación real del cobre existente.

## Política de routing aplicada

- `DIGITAL_LOW_SPEED`: preferencia por `B.Cu` en recorridos long-haul.
- `F.Cu`: escapes locales y bypasses puntuales donde la geometría lo exige.
- `UNO_IOREF_3V3`: conserva la clase `CONTROL_SENSITIVE`.
- `In1.Cu`: reservado a referencia GND; no se utiliza para señales.
- `In2.Cu`: no se utiliza para estas 16 señales.
- placement, outline, netlist y netclasses permanecen congelados.
- no se relaja ninguna regla DRC.

## Desarrollo del candidato

La familia de candidatos v13–v18 se trató como laboratorio efímero de Actions; ningún candidato parcial fue persistido como cobre de producción.

Principales aprendizajes:

1. **v13** consiguió conectividad 16/16, pero dejó 22 errores físicos y exceso de vías.
2. **v14** redujo el DRC a 5 errores, demostrando que los problemas estaban concentrados en microzonas y no en la estrategia general de capas.
3. Una penalización global de cambios de capa no resultó adecuada: algunas nets mejoraban, pero `PUMP_DIR` perdía resolubilidad.
4. La estrategia correcta fue optimizar el costo de vía por net/corredor y después corregir únicamente las microzonas físicas restantes.
5. **v18** alcanzó simultáneamente conectividad, DRC y calidad geométrica.

## ECO de routing previo: `CO2_ILIM`

El routing de `ACT_FAULT_N` reveló que los cuatro segmentos PR19A de `CO2_ILIM` formaban una garganta geométrica alrededor de `U_CO2_DRV.1`.

Se aplicó un ECO exclusivamente de geometría de cobre:

- net: `CO2_ILIM`;
- segmentos: **4 → 4**;
- vías: **0 → 0**;
- conectividad: sin cambios;
- netclass: sin cambios;
- placement: sin cambios;
- outline: sin cambios.

El recorrido final usa un muro en `x=216.20 mm`, conservando margen frente a `PUMP_CURRENT_ADC` y al escape de `ACT_FAULT_N`.

## ECO de spacing I²C

El candidato previo dejó dos vías `I2C_SDA` demasiado próximas entre taladros. La vía `(92.75, 15.50)` se desplazó a `(93.25, 15.50)` y se reanclaron sus dos segmentos adyacentes.

- conteo de vías: sin cambios;
- topología: sin cambios;
- conectividad: sin cambios;
- warning `hole_to_hole`: eliminado.

## Candidato aceptado — v18

Resultado del gate KiCad 10.0.5:

- **PR19C 16/16 conectado**.
- cobre nuevo PR19C: **362 segmentos / 88 vías**.
- acumulado PR19A+PR19B+PR19C: **917 segmentos / 119 vías**.
- DRC: **0 errores**.
- warnings: **255**, exactamente los históricos:
  - `silk_edge_clearance`: 13;
  - `text_height`: 1;
  - `silk_overlap`: 173;
  - `silk_over_copper`: 68.
- unconnected restantes: **154**.
- PR20A/PR20B: **0 nets con cobre adelantado**.
- `In1.Cu`: **0 signal tracks**.
- copper zones: **0**.
- placement y outline: congelados.

La caída de unconnected `192 → 154` coincide con las **38 conexiones lógicas** requeridas por el MST de las 16 nets del lote.

## Métricas geométricas por net

| Net | Segmentos | Vías | Giros | Longitud aprox. mm |
|---|---:|---:|---:|---:|
| `ACT_FAULT_N` | 41 | 8 | 20 | 397.733 |
| `CHILLER_CTL` | 20 | 4 | 13 | 296.208 |
| `CO2_SOL_CTL` | 22 | 8 | 11 | 278.925 |
| `HMI_RX` | 22 | 9 | 6 | 225.595 |
| `HMI_TX` | 21 | 8 | 7 | 227.908 |
| `HX711_DOUT` | 18 | 2 | 9 | 181.695 |
| `HX711_SCK` | 20 | 5 | 9 | 195.092 |
| `I2C_SCL` | 44 | 9 | 16 | 260.025 |
| `I2C_SDA` | 38 | 9 | 11 | 251.061 |
| `LED_STATUS` | 13 | 4 | 6 | 177.336 |
| `MCU_NRST` | 14 | 3 | 5 | 121.948 |
| `MCU_WDI` | 17 | 3 | 8 | 180.325 |
| `PUMP_DIR` | 23 | 8 | 12 | 276.892 |
| `PUMP_PWM` | 20 | 4 | 13 | 265.369 |
| `TEMP_1WIRE` | 17 | 2 | 6 | 91.013 |
| `UNO_IOREF_3V3` | 12 | 2 | 7 | 156.360 |

Todas las nets cumplen el gate de calidad PR19C de **≤10 vías por net** y permanecen holgadamente por debajo del límite de fragmentación de segmentos.

## Gate de aceptación

PR19C solo puede mergearse cuando el PCB persistido reproduce el candidato v18 y cumple simultáneamente:

- 16/16 nets PR19C conectadas;
- PR19A y PR19B preservados;
- exactamente 48 nets de los tres lotes con cobre;
- 11 nets PR20A/PR20B todavía diferidas;
- DRC errors = 0;
- warnings = los 255 históricos, sin tipos nuevos;
- unconnected = 154;
- `In1.Cu` sin señales;
- copper zones = 0;
- placement/outline sin cambios;
- workflows finales `contents: read`.

## Siguiente checkpoint

Después del merge de PR19C, el siguiente lote autorizado es **PR20A — 10 nets de potencia + salidas de actuadores**. No se inicia PR20A dentro de este PR.

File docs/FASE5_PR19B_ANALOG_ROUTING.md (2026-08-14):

# Fase 5 — PR19B: routing analógico long-haul

## Objetivo

Cerrar el segundo lote incremental de routing sobre el checkpoint PR19A sin modificar placement, outline, netlist ni reglas físicas.

## Alcance

PR19B materializa exclusivamente cuatro nets `ANALOG_SENSITIVE`:

- `PH_ADC`
- `ORP_ADC`
- `DO_ADC`
- `PUMP_CURRENT_ADC`

Las 27 nets de PR19C/PR20A/PR20B permanecen sin cobre.

## Topología aplicada

`PH_ADC`, `ORP_ADC` y `DO_ADC` resuelven sus conexiones locales en `F.Cu` y usan corredores long-haul anidados en `B.Cu` hacia `J_UNOQ`. `PUMP_CURRENT_ADC` sale de Z4, evita el corredor de switching/entrada de Z3 y cruza el corredor de `DO_ADC` mediante cambio controlado de capa en la banda superior.

No existe signal routing en `In1.Cu`; esa capa continúa reservada para el plano GND de PR20B. No se añadieron copper zones.

## Resultado físico

Sobre PR19A se añadieron:

- 32 segmentos;
- 7 vías;
- ancho de señal: 0.20 mm;
- vía mínima: 0.60/0.30 mm.

Checkpoint acumulado:

- PR19A: 28/28 nets preservadas;
- PR19B: 4/4 nets conectadas;
- 555 segmentos totales;
- 31 vías totales;
- 27 nets futuras sin cobre;
- `In1.Cu`: 0 signal tracks;
- copper zones: 0;
- unconnected: 192.

## DRC

KiCad 10.0.5: **0 errores**.

Se preserva exactamente la deuda conocida de 255 warnings, todos de texto/serigrafía:

- `silk_edge_clearance`: 13;
- `text_height`: 1;
- `silk_overlap`: 173;
- `silk_over_copper`: 68.

No se introdujo ningún nuevo tipo de violación.

## Gobernanza

La política `ALL_OR_NOTHING` se cumplió: el lote solo se acepta con 4/4 nets cerradas, DRC físico sin errores, PR19A intacto y lotes posteriores sin cobre.

El PCB persistido es `kicad/NFB_Insight_PCBA_v2.kicad_pcb`. La evidencia machine-readable vive en `hardware/pr19b_analog_routing_manifest.json` y `hardware/pr19b_analog_probe.json`; el gate final es `tools/validate_pr19b_analog.py`.

Siguiente checkpoint, únicamente después del merge: **PR19C — 16 nets digital/control inter-zona**.

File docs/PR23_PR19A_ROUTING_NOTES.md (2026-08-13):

# PR27 / PR19A — notas de routing local

## Alcance

PR27 materializa únicamente las **28 nets locales** definidas en `hardware/routing_batches_contract.json`. La política es `ALL_OR_NOTHING`: 28/28 o no merge.

El baseline autoritativo es el merge virtual `main` post-PR24/post-PR25/PR26 + rama PR27. Los runs `push` de la rama histórica no son evidencia de aceptación porque no incorporan los ECO de `main`; para aceptación se usan runs `pull_request` y, al final, el PCB persistido sobre el `main` vigente.

## Hallazgo: `5V_VCC` no debe tratarse como MST geométrico genérico

`5V_VCC` tiene tres endpoints con funciones físicas distintas:

- `U_5V.8` = `VCC`, salida del LDO interno del TPSM33625;
- `C_5V_VCC.1` = bypass local de VCC;
- `U_5V.11` = `RT` en la variante TPSM33625RDNR.

La configuración congelada del proyecto es `PIN11_RT_TO_PIN8_VCC`. La documentación primaria de TI para TPSM33625 establece que, en la variante con pin RT, **RT conectado a VCC selecciona 1 MHz**. La topología intencional queda `C_VCC→VCC` + `C_VCC→RT`, no un MST genérico.

## Clearances locales y KiCad

La excepción `0.125 mm` del TPSM33625 permanece estrictamente local a la garganta demostrada del encapsulado. No se permite reducir clearance global. KiCad 10.0.5 DRC continúa como autoridad física final.

## Pad-shape no equivale a endpoint eléctrico

El footprint `TI_RPW0010A_TPS259470A` usa pads compuestos. Todos los shapes siguen participando como geometría/obstáculos, pero el árbol de conectividad usa un solo endpoint lógico por `(ref,pin)`.

## Resultado autoritativo PR27 — primera materialización 28/28

Run `pull_request` #57 sobre el merge virtual vigente:

- **28/28 nets materializadas**;
- `1229` segmentos;
- `15` vías;
- `204` unconnected restantes, correspondientes al resto del board/lotes futuros;
- DRC ejecutado completamente;
- **60 errores físicos** y 257 warnings.

Los errores no están distribuidos aleatoriamente. Se concentran en pocas sub-islas:

| Dominio | Errores DRC | Causa dominante |
|---|---:|---|
| eFuse `OVLO/ILM/DVDT` | 29 | micro-rutas deterministas anteriores cruzan el corredor A* de OVLO |
| `LOAD_A_POS/NEG` | 11 | vías/rutas del árbol independiente invaden el pin del par opuesto |
| bomba `DIR/PWM/SR_CFG` | 8 | corredores F.Cu competidores junto a pines 1/3/4 del DRV8242 |
| CO₂ `ILIM/EN/OPENLOAD` | 6 | vías/escapes digitales interfieren con ILIM |
| `5V_FB` | 2 | aproximación a FBB demasiado cercana al pad GND |
| HMI field | 2 | vía TX demasiado próxima al pad RX de TXU0202 |
| chiller LED | 2 | vía LED_A demasiado próxima al pad 3V3 de R_CH_LED |

Tipos totales de error:

- `shorting_items`: 19;
- `tracks_crossing`: 18;
- `clearance`: 15;
- `hole_clearance`: 4;
- `solder_mask_bridge`: 4.

**Decisión:** no se corrigen 60 errores uno por uno. Se sustituyen las topologías de esas sub-islas por rutas deterministas simples y separadas.

## Plan correctivo por sub-isla

### eFuse

- `EFUSE_OVLO`: corredor izquierdo dedicado entre `U_EFUSE.2` y divisor R2/R3.
- `EFUSE_DVDT`: corredor exterior derecho en banda inferior-superior propia.
- `EFUSE_ILM`: corredor exterior aún más a la derecha y banda superior independiente.
- ITIMER/EN-UVLO se conservan si DRC sigue limpio.

### Load-cell / HX711

`LOAD_A_POS/NEG` dejan de ser dos árboles A* independientes. Se tratan como **par quieto**:

- troncales largas preferentemente B.Cu;
- escapes cortos F.Cu hacia `U_HX.8/7`;
- testpoints como ramas secundarias cortas;
- evitar vías junto a pads NC/HX y evitar cruce entre el par;
- objetivo ≤2 vías por net y topología paralela/auditable.

### Bomba

- `PUMP_SR_CFG` recibe corredor F.Cu inferior independiente.
- `PUMP_DIR_DRV`: breakout corto F.Cu, tramo B.Cu y retorno F.Cu; 2 vías.
- `PUMP_PWM_DRV`: corredor F.Cu separado.

### CO₂

- `CO2_ILIM` se lleva por corredor superior dedicado.
- `CO2_EN_DRV` queda en corredor inferior/local F.Cu.
- `CO2_OPENLOAD_N` usa una rama local F.Cu y el trayecto largo al TP por B.Cu con solo dos vías.

### HMI / chiller / 5V_FB

- `HMI_FIELD_TX`: tramo largo por B.Cu con vía alejada del TXU0202; rama local F.Cu.
- `CHILLER_LED_A`: F.Cu determinista, sin vía.
- `5V_FB`: unión corta `U_5V.9 → R_FBB.1 → R_FBT.2`, evitando el pad GND de FBB.

## Calidad geométrica pendiente aun después de DRC

Aunque no generaron los 60 errores, estas rutas son demasiado fragmentadas para aceptar como producción:

- `5V_PGOOD`: 143 segmentos / 69.623 mm;
- `CO2_OPENLOAD_N`: 106 segmentos / 52.025 mm (se corrige con la topología anterior);
- `WDT_MR_N`: 100 segmentos / 47.733 mm;
- `LOAD_A_NEG`: 98 segmentos / 4 vías / 47.985 mm;
- `LOAD_A_POS`: 91 segmentos / 44.655 mm.

Una vez eliminado DRC físico, `5V_PGOOD` y `WDT_MR_N` deben simplificarse antes de merge aunque el gate formal antiguo de 220 segmentos los tolerase.

## Gate de aceptación

PR27 no se mergea hasta cumplir simultáneamente:

- 28/28 conectadas;
- 0 nets de los otros 31 nets con cobre;
- **DRC errors = 0**;
- 0 shorts/clearance/courtyard/hole-clearance/solder-mask-bridge nuevos;
- In1.Cu sin signal tracks;
- sin copper zones;
- placement/outline/footprints/netlist congelados;
- rutas excesivamente fragmentadas simplificadas;
- `.kicad_pcb` final persistido en la rama sobre el `main` vigente;
- CI final read-only;
- `README.md` actualizado al estado real antes del merge.

Además, el validador debe comparar orientaciones módulo 360 (`270° ≡ -90°`) para no generar falsos negativos de placement.

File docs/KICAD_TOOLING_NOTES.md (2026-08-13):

# NFB Insight PCBA v2 — notas técnicas de tooling KiCad

Referencia técnica para scripts `pcbnew`, validadores y CI de NFB Insight PCBA v2. Estas notas destilan hallazgos propios PR17–PR24 y conocimiento reusable verificado en el repo donor `nebula_qshield_pcb`. **No se hereda geometría ni layout del donor.**

## 1. El triplete de KiCad es inseparable en pruebas

Para este proyecto existen:

- `kicad/NFB_Insight_PCBA_v2.kicad_pcb`
- `kicad/NFB_Insight_PCBA_v2.kicad_pro`
- `kicad/NFB_Insight_PCBA_v2.kicad_dru`

Si un test copia el PCB a otro basename, debe copiar también `.kicad_pro` y `.kicad_dru` con ese mismo basename. De lo contrario `kicad-cli` puede evaluar el board con reglas genéricas diferentes a las reglas efectivas del proyecto y producir falsos resultados.

**Regla CI:** preferir validar el board canónico. Si se necesita sandbox, clonar el triplete completo.

## 2. `.kicad_pro` y `.kicad_dru` cumplen papeles distintos

`*.kicad_pro` contiene valores de proyecto/netclass, incluidos anchos preferidos. `*.kicad_dru` contiene reglas custom que pueden imponer mínimos o excepciones locales diferentes.

El router no debe asumir que `track_width` de `.kicad_pro` es automáticamente el mínimo legal. Antes de implementar neckdown o rutas críticas, calcular la regla efectiva aplicable a la net y dejar que `kicad-cli pcb drc` sea la autoridad final.

En NFB existe ya una excepción localizada del TPSM33625: clearance interno de `0.125 mm` exclusivamente para geometría asociada a `U_5V`; no debe convertirse en una relajación global.

## 3. `PCB_VIA.GetWidth()` necesita capa

Evitar:

```python
via.GetWidth()
```

Usar:

```python
via.GetWidth(pcbnew.F_Cu)
```

La llamada sin capa puede disparar un assert nativo y bloquear el proceso en lugar de producir una excepción Python manejable.

## 4. Courtyard real ≠ `footprint.GetBoundingBox()`

Para placement, ECO y keepouts, no usar el bounding box global del footprint como sustituto de courtyard. Puede incluir Fab, texto u otros gráficos.

Calcular el courtyard desde `fp.GraphicalItems()` filtrando ítems por `F.Courtyard` / `B.Courtyard` y construir el bounding box a partir de esa geometría.

Esto es crítico para los gates que exigen `courtyard overlaps = 0`.

## 5. Clearance propio con margen positivo

Los scripts geométricos usan coordenadas discretizadas y pueden acumular errores submicrónicos. Un chequeo propio nunca debe ser permisivo respecto al límite DRC.

Ejemplo recomendado: exigir margen positivo adicional (orden `0.01 mm` cuando sea apropiado) antes de considerar un corredor disponible. El valor exacto no sustituye la regla de KiCad: solo evita falsos positivos del planner.

**Autoridad final:** DRC KiCad 10.0.5.

## 6. Pad-shape no equivale a endpoint eléctrico

Algunos footprints usan varios shapes con el mismo número de pad. Para routing/connectivity:

- todos los shapes siguen participando como cobre/obstáculos;
- pero un mismo `ref.pin` representa **un endpoint eléctrico lógico**.

Este hallazgo fue crítico en PR23 para el TPS259470A: contar cada shape como endpoint separado generaba árboles de routing artificiales y cobre innecesario.

## 7. Nets multipunto: no imponer MST geométrico ciegamente

La topología eléctrica debe preceder al árbol geométrico.

Ejemplos ya demostrados:

- `5V_VCC`: el capacitor VCC es centro físico/funcional y el strap RT→VCC tiene propósito de configuración; un MST genérico generaba una unión innecesariamente difícil pin8→pin11.
- divisores/programación eFuse: ITIMER/UVLO/OVLO/ILM/DVDT requieren priorización por confinamiento físico y función, no solo por distancia.
- `LOAD_A_POS/NEG`: deben tratarse como par quieto principal `J_LOADCELL → U_HX`; los testpoints son ramas secundarias cortas.

## 8. Micro-ruta determinista cuando la grilla no representa un corredor legal

Una grilla A*/Dijkstra puede no muestrear una garganta física real aun cuando DRC permita un camino. En ese caso:

1. medir geometría exacta;
2. demostrar que el corredor existe;
3. usar waypoints continuos/locales solo para esa micro-ruta;
4. mantener netclass/clearance;
5. validar con DRC.

No reducir globalmente la rejilla o el clearance para resolver un solo pin.

## 9. Neckdown: siempre local, documentado y DRC-gated

Si una salida de pitch fino requiere ancho/clearance especial:

- limitarla a una net concreta;
- limitarla a una región/courtyard concreta;
- no debilitar reglas fuera de esa microzona;
- documentar el motivo eléctrico/físico;
- exigir DRC completo.

Un neckdown que “hace que el router encuentre camino” pero produce un nuevo error DRC se rechaza.

## 10. `unconnected_items` no significa automáticamente “dibujar una pista”

Antes de rutear un ítem reportado como desconectado:

- identificar net y endpoints reales;
- reconstruir conectividad de board;
- diferenciar pads/tracks/vías de islas de plano;
- cuando existan zones, detectar posibles pares `Zone ↔ Zone` espurios del refill/island detector.

En PR19A todavía no se materializan planos de GND/potencia; esta regla cobrará más importancia en PR20A/PR20B.

## 11. Refill de zones y conectividad

Cuando un cambio futuro afecte zones:

```python
filler = pcbnew.ZONE_FILLER(board)
filler.Fill(board.Zones())
```

No asumir continuidad de un plano por inspección visual. Confirmar cobre relleno/conectividad real mediante APIs de zone/connectivity y después DRC.

## 12. PCB regenerado: equivalencia semántica, no byte-a-byte

`pcbnew` puede regenerar UUIDs al reconstruir footprints/board. Por eso PR17 abandonó la expectativa de `git diff` cero para el `.kicad_pcb` regenerado.

Validar semánticamente:

- refs;
- XY/rotación;
- `LIB_ID`/footprints;
- pads/nets;
- board outline;
- layer/routing policy;
- DRC;
- métricas del lote.

Los JSON deterministas sí pueden exigir reproducción byte/text exacta cuando corresponda.

## 13. CI de validación debe ser read-only

No persistir automáticamente un `.kicad_pcb` reconstruido en cada corrida: los UUIDs no byte-estables pueden crear bucles de commits del bot.

Patrón vigente:

- persistencia explícita y excepcional cuando un artefacto ya pasó DRC;
- después, workflow final con `permissions: contents: read`;
- HEAD normal de usuario/agente revalida antes del merge.

## 14. Gates históricos deben ser composicionales

Un gate antiguo no debe asumir que su revisión sigue siendo la última.

Ejemplo ya aplicado:

- PR22 valida su ECO Z3 contra PR17;
- después aplica PR24 Z2;
- finalmente compara/reconstruye el estado vigente completo.

Cada ECO futuro debe preservar esta cadena: **validar el delta local contra su baseline y luego reproducir todos los ECO posteriores vigentes**.

## 15. Placement global congelado, ECO local permitido con evidencia

Routing puede revelar un problema real de placement. No se debe forzar cobre alrededor de una mala microtopología.

Un ECO post-PR17 requiere:

- trigger reproducible desde routing;
- evidencia primaria o inferencia de ingeniería declarada;
- mínimo número de refs movidas;
- resto de refs idénticas;
- courtyard overlaps = 0;
- DRC físico = 0;
- contrato JSON + script reproducible;
- merge del ECO antes de reiniciar el lote de routing.

Aplicado ya en:

- PR22: 5 pasivos de la isla TPSM33625;
- PR24: 2 testpoints de load-cell junto a HX711.

## 16. Calidad geométrica además de conectividad

Una ruta conectada puede seguir siendo inaceptable.

Métricas mínimas por net/lote:

- longitud total;
- número de segmentos;
- número de vías;
- giros/cambios de dirección;
- capa(s);
- corredor/zona;
- relación con nets sensitive/dirty.

Ejemplo de anti-patrón detectado en PR23: una net local podía cerrar con ~200 segmentos y múltiples vías. Esa ruta no debe mergearse solo por estar eléctricamente conectada.

## 17. Política de routing incremental NFB

Contrato vigente:

`28 locales → 4 analógicas inter-zona → 16 digital/control → 10 potencia/actuadores → 1 GND`

Cada lote es **ALL_OR_NOTHING**:

- 100% de sus nets conectadas;
- 0 nets de lotes futuros con cobre;
- 0 shorts/clearance/courtyard nuevos;
- placement/outline fuera de scope congelados;
- métricas razonables;
- DRC acorde a la fase.

## 18. Fuente donor: qué se hereda y qué no

Del repo `Nhilson73/nebula_qshield_pcb` se heredan únicamente aprendizajes/tooling generalizable: gotchas `pcbnew`, DRC, courtyards, triplete de basename, tratamiento de zones y estrategias de routing.

**No heredar:** dimensiones, coordenadas, J21, layout 170×120, netclasses concretas, copper, placement, keepouts ni topology específica del Q-Shield.

NFB Insight conserva su propia geometría contractual **242.34 × 68.58 mm** y sus contratos PR17–PR24 como autoridad.

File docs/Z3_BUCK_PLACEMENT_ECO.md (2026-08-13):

# ECO de placement Z3 — TPSM33625

## Contexto

Durante PR19A, el routing de las 28 nets locales reveló que la micro-isla del convertidor `U_5V = TPSM33625RDNR` había sido organizada por el empaquetador geométrico PR17, pero no suficientemente por prioridad eléctrica. El síntoma fue reproducible: `5V_FB` y `5V_VCC` podían rutearse individualmente, pero se bloqueaban mutuamente al intentar cerrar ambas con clearances físicos conservadores.

La decisión fue **no forzar routing alrededor de un placement subóptimo** y no relajar DRC. Se abrió un ECO local de placement antes de continuar el lote.

## Fuente primaria

Autoridad primaria: **Texas Instruments, TPSM33625, datasheet SNVSCB1D Rev. D, sección 8.5.1 — Layout Guidelines**.

La intención relevante de TI es:

- capacitores de entrada tan cerca como sea posible de `VIN/GND`;
- capacitor bypass de `VCC` cerca del pin `VCC`, con conexiones cortas y anchas a `VCC/GND`;
- divisor `R_FBT/R_FBB` tan cerca como sea posible de `FB`, con recorridos `FB/GND` cortos.

El ECO traduce esas prioridades a coordenadas reproducibles dentro de Z3.

## Alcance

Solo se mueven/rotan cinco referencias:

- `C_5V_IN_4U7`
- `C_5V_IN_100N`
- `C_5V_VCC`
- `R_5V_FBT`
- `R_5V_FBB`

`U_5V` permanece fijo. No cambian:

- outline `242.34 × 68.58 mm`;
- altura `68.58 mm`;
- zonas Z0–Z4;
- netlist;
- footprints;
- secuencia FIELD I/O;
- arquitectura de potencia;
- routing/cobre.

El contrato machine-readable es `hardware/z3_buck_placement_eco.json`.

## Targets congelados

| Ref | X mm | Y mm | Rotación | Intención |
|---|---:|---:|---:|---|
| `C_5V_IN_4U7` | 184.600 | 19.075 | 180° | VIN bulk, pad VIN orientado hacia la isla |
| `C_5V_IN_100N` | 188.950 | 19.075 | 180° | bypass HF de entrada más próximo a U_5V |
| `R_5V_FBT` | 191.600 | 15.390 | 90° | divisor FB vertical bajo el borde FB |
| `R_5V_FBB` | 193.000 | 15.390 | 270° | divisor FB vertical bajo FB/GND |
| `C_5V_VCC` | 195.300 | 15.600 | 0° | bypass VCC inmediatamente bajo VCC/GND |

## Validación

El flujo PR22 exige:

1. regenerar el placement base PR17;
2. aplicar exactamente cinco movimientos;
3. demostrar que las otras **114 referencias** no cambian;
4. reconstruir el PCB desde la base KiCad;
5. validar XY/rotación/footprints/nets y courtyards;
6. exigir `tracks/vías/zones = 0`;
7. ejecutar DRC completo de KiCad.

Resultado físico observado antes de persistencia:

- referencias movidas: 5;
- referencias sin cambio: 114;
- courtyard overlaps: 0;
- DRC errors: 0;
- shorts/clearance/courtyard violations: 0;
- unconnected: 250, esperado por placement-only;
- deuda silk/text: 259 warnings, todos tipificados; el incremento respecto PR17 fue `+13 silk_over_copper` y debe eliminarse antes de artwork/Gerbers.

## Regla de ingeniería derivada

**El placement global está congelado, pero el routing puede abrir un ECO local cuando descubre una debilidad física/electromagnética que no debe resolverse con trazas artificiales.** Para admitir el ECO deben cumplirse simultáneamente:

- evidencia técnica primaria;
- mínimo número de referencias afectadas;
- cero cambios de arquitectura/netlist/outline salvo necesidad explícitamente aprobada;
- regeneración determinista;
- DRC físico sin errores;
- aprendizaje documentado antes de continuar routing.

PR19A solo se reinicia después de que este ECO quede mergeado y reproducible desde `main`.

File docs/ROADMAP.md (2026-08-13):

# NFB Insight PCBA v2 — Hoja de Ruta de Desarrollo

## Regla transversal

- [x] UNO Q: repos oficiales `arduino/*` en GitHub = fuente primaria.
- [x] Jerarquía en `docs/SOURCE_OF_TRUTH.md`.
- [x] No inventar land patterns ni keepouts RF no publicados.
- [x] README se actualiza cuando cambia arquitectura, BOM, compliance o estado.
- [x] JSON/BOM permanecen como autoridad eléctrica; KiCad generado es reproducible semánticamente.

## Fase 0 — Arquitectura

- [x] Herencia selectiva desde Q-Shield.
- [x] UNO Q rotado, USB-C `-Y`, altura `68.58 mm`, crecimiento `+X`.
- [x] `Y=0` FIELD I/O EDGE y zonas Z0–Z4.

## Fase 1 — Mecánica UNO Q

- [x] Footprint mecánico, agujeros y referencias UNO Q.
- [x] Contorno inicial `68.58 × 220 mm` provisional.
- [x] DRC/validación mecánica automática.
- [x] PR #16: Z0 completo congelado como host envelope sin footprints NFB.
- [x] PR #16: fuente Arduino revalidada; no se inventa antenna keepout numérico ausente de fuente primaria.
- [x] PR #17: ancho final de placement congelado en `242.34 mm` por courtyards reales.
- [ ] Revisión 3D/enclosure y región RF del host después del routing preliminar.

## Fase 2 — Arquitectura eléctrica Insight

### PR #3–#7 — contratos Z0/Z1/Z2
- [x] 32 pads UNO Q + snapshot firmware.
- [x] Interfaces reales pH/ORP/DO, TEMP DS18B20, MPR `0x28`.
- [x] Z1 netlist/BOM/gates.
- [x] Z2 HX711, DFR1103 `0x66`, HMI TXU0202, watchdog.
- [x] A4=`PUMP_CURRENT_ADC`; `CO2_ADC` continúa prohibido.

### PR #8 — EU Compliance Design Gate
- [x] Frontera shield/carrier y RF UNO Q preservada.
- [x] EMC / RoHS 3 / WEEE / RED / REACH / CE.
- [x] CI para GND, ESD, ruido, RF y evidencia.
- [ ] Archivar certificados/DoC del SKU UNO Q final en expediente release.
- [ ] Confirmar normas/plan de laboratorio final.

## Fase 3 — Potencia, actuadores e integración EDA

### PR #9 / PR #10 — potencia de producción
- [x] PR #9: 12 V protegido → VIN UNO Q.
- [x] PR #9: rails locales 5 V / 3.3 V sin back-feed.
- [x] PR #10: `TPS259470ARPWR` + `SMBJ15A`.
- [x] PR #10: `TPSM33625RDNR` 1 MHz + `TLV75533PDBVR`.
- [x] PR #10: `12V_HOST_VIN / 12V_LOGIC / 12V_ACT`; chiller power externa.
- [x] PR #10: netlist/BOM/netclasses/`power.kicad_sch` + ERC.
- [ ] DC-bias efectivo 2×22 µF ≥25 µF.
- [ ] HIL/termografía 60 °C e inrush `F_ACT`.

### PR #11 / #12 — integración + Z4
- [x] Audit machine-readable de footprints.
- [x] Bomba `DRV8242HQRHLRQ1`, D5/D6, IPROPI→A4.
- [x] Solenoide `TPS1HC120CQDYCRQ1`, D7, ILIM ~0.5 A.
- [x] Chiller `AQY212EHAX`, dry contact SELV ≤48 V / NO MAINS.
- [x] D10=`ACT_FAULT_N`.
- [ ] Migrar firmware A4/D10.

### PR #13 — cierre de footprints críticos
- [x] Spark como cross-check independiente, no autoridad.
- [x] RPW0010A — TI `4225183/A`.
- [x] RDN0011A — TI `4226623/F`.
- [x] RHL0020B — TI `4226154/B`.
- [x] DYC0008A — TI `4226548/B`, 8 pads sin PowerPAD.
- [x] AQY212EHAX SMD — Panasonic exacto.
- [x] 9/9 gates verdes; sin placement/routing.

### PR #14 — root EDA inter-zona
- [x] Root Z0–Z4 real.
- [x] GND Z0–Z4; 3V3/5V locales excluyen Z0.
- [x] I²C Z0/Z1/Z2; `12V_ACT` Z3/Z4; controles Z0/Z4.
- [x] Deuda transitoria controlada 125 `label_dangling`.
- [x] 11/11 gates verdes y merge.

### PR #15 — hierarchy de producción
- [x] Z0–Z4 generados desde pin-contract/netlists/BOM.
- [x] UUIDs deterministas + `NFB_GEN`.
- [x] Paridad refs/pines/nets/footprints JSON↔BOM↔KiCad.
- [x] TXU0202/DCU0008A, Phoenix 1757242 y Littelfuse 045401.5MR cerrados.
- [x] Deuda PR #14 eliminada.
- [x] KiCad 10.0.5: **ERC 0 Errors / 0 Warnings**.
- [x] Placement/routing permanecieron en cero.

## Fase 4 — Placement

### PR #16 — pre-placement readiness
- [x] Revalidar `arduino/docs-content` actual antes del placement.
- [x] Snapshot PR16: `24445a32e249d410c1e4359bdc99d8c0dcb17bd2`.
- [x] Confirmar WCBN3536A/WCN3980 + shared PCB antenna.
- [x] No inventar antenna keepout numérico no publicado.
- [x] Z0 `0…53.34 × 0…68.58 mm` prohibido para production footprints NFB.
- [x] Z1 quiet inmediatamente adyacente; Z3/Z4 ruidosos desplazados a +X.
- [x] Congelar `In1.Cu` como plano GND continuo / no signal routing.
- [x] Congelar orden FIELD I/O izquierda→derecha.
- [x] Cerrar `J_LOADCELL` a Phoenix Contact `1757268` / 5.08 mm.
- [x] Congelar reglas ESD/analog/HX711/HMI/power/actuator proximity.
- [x] `hardware/placement_readiness_contract.json` + CI.
- [x] Mantener production placement=0 y routing=0 durante PR16.
- [x] Full CI PR #16 + merge.

### PR #17 — placement físico
- [x] Colocar Z1 FIELD I/O y front-ends por courtyards reales.
- [x] Colocar Z2 load-cell/GNSS/HMI respetando gradiente quiet→power.
- [x] Colocar Z3 power-entry/eFuse/buck/LDO con loops de placement compactos.
- [x] Colocar Z4 drivers/bulk/conectores junto al FIELD I/O EDGE.
- [x] Mantener Z0 inmutable y libre de production footprints NFB.
- [x] Ajustar ancho exclusivamente hacia +X: `242.34 mm` final de placement.
- [x] Test points accesibles en banda superior.
- [x] Courtyard overlaps = 0; sin shorts/clearance físicos de placement.
- [x] Corrección Honeywell MPR y regla local TPSM33625 verificadas.
- [x] **Routing continuó prohibido: 0 tracks / 0 vías / 0 zones.**
- [x] PR #17 mergeado; layout revisado visualmente antes de seguir.
- [ ] Revisión 3D/enclosure/RF del conjunto físico.

## Fase 5 — Routing incremental

### PR #18 — routing readiness / contrato de cobre
- [x] Congelar board y placement PR17: `242.34 × 68.58 mm`.
- [x] Clasificar exactamente 59/59 nets de producción una sola vez.
- [x] Mantener mínimos de potencia PR10 sin debilitarlos.
- [x] `In1.Cu` = GND continuo; signal routing prohibido.
- [x] `In2.Cu` reservado a distribución de potencia/retornos controlados.
- [x] Congelar analógica sensible: pH/ORP/DO, load-cell/HX711 y `PUMP_CURRENT_ADC`.
- [x] Congelar dirty nets: `12V_ACT`, `PUMP_OUT1/2`, `CO2_SOL_POS`.
- [x] Separación contractual sensitive↔dirty ≥ `1.00 mm` en recorridos paralelos.
- [x] Chiller dry-contact: SELV ≤48 V / NO MAINS / sin tie a GND.
- [x] Prohibir `SW`, `CO2_ADC`, `TEMP_ADC`, `HUM_ADC`, `CO2_PWM`, `CO2_FLOW_PWM`, `RS485_IRQ_RSVD`.
- [x] CI PR18 exige 0 tracks / 0 vías / 0 copper zones.
- [x] Full CI PR #18 + merge.

### PR #19 experimental — cerrado sin merge
- [x] Medir endpoints/carriles de las 59 nets.
- [x] Probar escapes finos TPSM33625 / TPS259470A / TPS1HC120.
- [x] Confirmar frontera natural de 28 nets locales antes del long-haul.
- [x] Detectar que long-haul monolítico produce congestión y rutas con demasiados segmentos.
- [x] Cerrar PR #19 sin merge y preservar su rama como laboratorio/evidencia.
- [x] Documentar aprendizaje en `docs/ROUTING_KNOWLEDGE_BASE.md`.
- [x] Congelar partición machine-readable en `hardware/routing_batches_contract.json`.

### PR19A — lote local, 28 nets
- [ ] Rutear exactamente 28/28 nets locales.
- [ ] 0 nets PR19B/PR19C/PR20A/PR20B tocadas.
- [ ] Mantener `In1.Cu` sin signal routing.
- [ ] DRC: 0 shorts y 0 errores nuevos de clearance/courtyard.
- [ ] Registrar segmentos/vías/longitud/calidad geométrica por net.
- [ ] Revisión visual del lote antes de merge.
- [ ] Merge solo 28/28; política ALL_OR_NOTHING.

### PR19B — lote analógico inter-zona, 4 nets
- [ ] `PH_ADC`.
- [ ] `ORP_ADC`.
- [ ] `DO_ADC`.
- [ ] `PUMP_CURRENT_ADC` por corredor silencioso Z4→Z0, evitando switching Z3.
- [ ] Revisar retorno contra futuro plano GND.
- [ ] Merge solo 4/4.

### PR19C — lote digital/control inter-zona, 16 nets
- [ ] Rutear 16/16 low-speed/control long-haul.
- [ ] Preferir B.Cu para troncales; F.Cu para escapes locales.
- [ ] Mantener clocks/I²C alejados de front-end analógico.
- [ ] Limitar giros/vías y rechazar rutas meandriformes aunque conecten.
- [ ] Merge solo 16/16.

### PR20A — potencia + salidas de actuadores, 10 nets
- [ ] Rutear 7 nets de potencia con anchos/clearances PR18.
- [ ] Rutear `PUMP_OUT1`, `PUMP_OUT2`, `CO2_SOL_POS` confinadas a Z4.
- [ ] `12V_ACT` y retornos high-current sin atravesar Z1/Z2.
- [ ] Usar F.Cu/In2.Cu según contrato y revisar trayectoria de corriente.
- [ ] Merge solo 10/10.

### PR20B — GND / plano + stitching, 1 net
- [ ] Materializar `GND` continuo en `In1.Cu`.
- [ ] Conectar los 83 endpoints identificados por el probe experimental.
- [ ] Añadir stitching controlado.
- [ ] Revisar retornos quiet/dirty y continuidad del plano.
- [ ] Exigir cierre completo de conectividad antes de artwork.

### Regla de merge Fase 5
- [x] Partición exhaustiva y mutuamente excluyente: `28 + 4 + 16 + 10 + 1 = 59`.
- [x] Política `ALL_OR_NOTHING` por lote.
- [x] CI falla ante net duplicada, faltante o fuera de lote.
- [ ] Ningún lote se mergea parcialmente.

## Fase 6 — Fabricación / compliance

- [ ] Lifecycle y fuentes calificadas.
- [ ] Todos los footprints auditados en release BOM/CPL.
- [ ] RoHS3/REACH PCB+BOM+ensamblaje.
- [ ] Evidencia UNO Q archivada.
- [ ] Pre-compliance EMC/ESD/inmunidad.
- [ ] Gerbers/drill + BOM + CPL + stackup.
- [ ] Tag `v2.0-RC1` tras gates.

## Fase 7 — Bring-up / HIL

- [ ] Rails, secuencia y ausencia de back-feed.
- [ ] Termografía 60 °C.
- [ ] Sensores Z1 + Z2.
- [ ] Bomba PWM/DIR/IPROPI/stall/inrush/fault.
- [ ] Solenoide current/open-load/fault/clamp.
- [ ] Chiller dry contact SELV/fail-safe.
- [ ] D10 `ACT_FAULT_N` y firmware failsafe.
- [ ] Pre-scan EMC con cables/actuadores reales.
- [ ] Fixture HIL repetible.

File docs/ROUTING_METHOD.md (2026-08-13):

# Método de routing por lotes

El routing se ejecuta de menor a mayor acoplamiento físico:

1. 28 nets locales.
2. 4 nets analógicas inter-zona.
3. 16 nets digital/control inter-zona.
4. 10 nets de potencia + actuadores.
5. GND como plano continuo In1 + stitching.

Cada lote parte del `main` verde del lote anterior y solo se mergea completo. Los intentos exploratorios viven fuera de `main`.

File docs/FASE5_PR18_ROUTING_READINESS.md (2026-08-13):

# Fase 5 — PR #18: Routing Readiness

## Objetivo

PR #18 convierte el placement aprobado del PR #17 en una base segura para iniciar routing. **No añade cobre.** Congela clases, capas, dominios de ruido, retornos y reglas de cruce antes de que PR #19 materialice pistas, vías o planos.

## Geometría heredada e inmutable

- Origen global: `(0,0)`.
- USB-C UNO Q: `-Y`.
- FIELD I/O EDGE: `Y=0`, cables hacia `-Y`.
- Board: `242.34 × 68.58 mm`.
- Crecimiento permitido: únicamente `+X`, aunque PR #18 no cambia geometría.
- Z0: `0.00 → 53.34 mm`.
- Z1: `53.34 → 108.84 mm`.
- Z2: `108.84 → 163.34 mm`.
- Z3: `163.34 → 198.34 mm`.
- Z4: `198.34 → 242.34 mm`.

PR #18 no puede modificar XY, rotaciones, footprints, board outline ni netlists.

## Política de capas

| Capa | Intent congelado |
|---|---|
| `F.Cu` | loops locales, front-end analógico y conexiones críticas/cortas |
| `In1.Cu` | **GND continuo; signal routing prohibido** |
| `In2.Cu` | distribución de potencia; sin señales analógicas sensibles |
| `B.Cu` | señales secundarias/low-speed y recorridos largos cuando convenga |

Dentro de Z0 solo se permitirán en PR #19 escapes directos y mínimos desde/hacia pads de `J_UNOQ`. No se permiten loops de switching ni salidas de actuadores en Z0.

La fuente primaria Arduino revisada no publicó una distancia numérica de keepout de antena; por tanto NFB no inventa una. La revisión de cobre/enclosure/RF sigue siendo gate de release.

## Cobertura de nets

`hardware/routing_contract.json` clasifica exactamente las **59 nets de producción**, una sola vez cada una. El gate CI falla ante:

- una net sin clase;
- una net asignada a dos clases;
- una net extra;
- reaparición de nets prohibidas;
- debilitamiento de las clases de potencia congeladas desde PR #10.

## Dominios de routing

### Entrada y potencia

- `12V_IN_RAW` / `12V_PROTECTED`: clase `PWR_INPUT_5A`, mínimo `2.00 mm`, clearance `0.50 mm`.
- `12V_HOST_VIN` / `12V_LOGIC` / `12V_ACT`: `PWR_12V_BRANCH`, mínimo `1.00 mm`.
- `5V_RAIL`: mínimo `0.75 mm`.
- `3V3_RAIL`: mínimo `0.40 mm`.
- `12V_ACT` no atraviesa Z1/Z2.

### Actuadores

`PUMP_OUT1`, `PUMP_OUT2` y `CO2_SOL_POS` forman `ACTUATOR_OUTPUT`. Permanecen en Z4, alejados de analógica sensible, y sus retornos deben cerrar hacia la estrella Z3/Z4 sin cruzar Z1/Z2.

### Analógica sensible

`PH_ADC`, `ORP_ADC`, `DO_ADC`, `LOAD_A_POS`, `LOAD_A_NEG`, `HX_VBG` y `PUMP_CURRENT_ADC` forman `ANALOG_SENSITIVE`.

Reglas especiales:

- referencia continua a `In1.Cu/GND`;
- separación paralela mínima contractual de `1.00 mm` frente a nets dirty;
- load-cell como par quieto desde `J_LOADCELL` hasta `U_HX`;
- `PUMP_CURRENT_ADC`, al cruzar desde Z4 hasta UNO Q, debe usar el corredor más silencioso disponible y evitar los loops de entrada/buck de Z3.

### Front-end de campo

`PH_FIELD_SIG`, `ORP_FIELD_SIG` y `DO_FIELD_SIG` son locales de Z1 y deben permanecer lo más cortos posible entre conector, ESD/protección y acondicionamiento. Vías antes del nodo acondicionado quedan fuertemente desaconsejadas.

### Control sensible

Feedback/programación de eFuse/buck, `PUMP_SR_CFG` y `CO2_ILIM` permanecen locales a sus IC. El `TPSM33625` no expone un nodo SW externo; una net de producción llamada `SW` queda prohibida.

### Chiller

`CHILLER_CONTACT_A/B` forman `CHILLER_DRY_CONTACT`:

- SELV `≤48 V` solamente;
- **NO MAINS**;
- confinadas a Z4/lado aislado del PhotoMOS;
- sin unión intencional a GND ni a rails lógicos.

## Estado DRC heredado

PR #17 cerró errores físicos de placement. PR #18 conserva exactamente el mismo PCB sin routing:

- tracks = `0`;
- vías = `0`;
- copper zones = `0`;
- deuda de `unconnected_items` permanece intencional hasta PR #19;
- warnings de silkscreen/rotulación siguen acotados y no habilitan Gerbers.

## Gate para PR #19

PR #19 podrá materializar cobre únicamente si PR #18 demuestra:

1. 59/59 nets cubiertas una sola vez;
2. netclasses de potencia PR #10 no debilitadas;
3. board y placement PR #17 intactos;
4. `In1.Cu` congelado como GND sin señales;
5. cero tracks/vías/zones introducidos por PR #18;
6. CI completo verde.

PR #19 será el primer PR autorizado para routing físico.

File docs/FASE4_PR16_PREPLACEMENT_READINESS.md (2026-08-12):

# PR #16 — Pre-placement Readiness

**Objetivo:** autorizar la siguiente fase de placement XY sin introducir todavía ningún footprint de producción en `kicad/NFB_Insight_PCBA_v2.kicad_pcb`.

**Contrato machine-readable:** `hardware/placement_readiness_contract.json`  
**Gate:** `tools/validate_placement_readiness.py`

## 1. Revalidación UNO Q antes del placement

PR #16 vuelve a consultar primero `arduino/docs-content`, siguiendo `docs/SOURCE_OF_TRUTH.md`.

Snapshot revisado:

`24445a32e249d410c1e4359bdc99d8c0dcb17bd2`

Archivos:

- `content/hardware/02.uno/boards/uno-q/product.md`
- `content/hardware/02.uno/boards/uno-q/datasheet/datasheet.md`
- `content/hardware/02.uno/boards/uno-q/tech-specs.yml`

La fuente oficial identifica `WCBN3536A / Qualcomm WCN3980` y una **shared PCB antenna**. También mantiene el concepto de shields/carriers como expansión oficial del UNO Q y publica evidencia de certificación del host.

## 2. Política RF: no inventar un keepout

La documentación fuente revisada no publica una distancia textual de antenna keepout que podamos convertir honestamente a milímetros.

Por tanto PR #16 **no crea una cifra RF ficticia**. En su lugar congela una frontera física verificable:

- Z0 UNO Q = `X 0…53.34 mm`, `Y 0…68.58 mm`;
- ningún footprint de producción NFB puede ocupar Z0;
- el shield crece únicamente desde `X=53.34 mm` hacia `+X`;
- la primera zona adyacente es Z1 sensores/quiet;
- switching/potencia se mantiene en Z3 y actuadores/high-current en Z4;
- no se permite que enclosure metálico, brackets, cable shields o PCBs apiladas invadan la región RF del host sin validación 3D/RF.

Los guides actuales colocan Z3 a `X≥145 mm` y Z4 a `X≥180 mm`. Esto deja 91.66 mm y 126.66 mm respectivamente desde el borde +X de Z0. **Son separaciones derivadas del zoning NFB, no especificaciones RF de Arduino.**

## 3. Stackup intent antes de placement

El PCB sigue siendo de cuatro capas. PR #16 congela el propósito de capas para evitar repetir el problema del donor Q-Shield:

- `F.Cu`: componentes + señales locales/críticas;
- `In1.Cu`: **plano GND continuo de referencia, sin signal routing**;
- `In2.Cu`: distribución de potencia manteniendo geometría de retornos quiet/dirty;
- `B.Cu`: señales secundarias/low-speed.

Un autorouter no podrá reutilizar `In1.Cu` como capa de señal.

## 4. FIELD I/O EDGE

Todos los conectores/cables de proceso se organizan sobre `Y=0` con salida `-Y`, excepto el MPR cuyo puerto de presión es vertical y debe quedar accesible cerca del borde.

Secuencia izquierda→derecha congelada para PR #17:

1. `J_PH`
2. `J_ORP`
3. `J_TEMP`
4. `U_CO2` — puerto vertical
5. `J_DO`
6. `J_LOADCELL`
7. `J_GNSS_RTC`
8. `J_HMI`
9. `J_PWR_IN`
10. `J_PUMP`
11. `J_CO2_SOL`
12. `J_CHILLER_CTL`

La secuencia conserva el gradiente **sensible → digital → potencia → actuadores**.

## 5. Cierre adicional de J_LOADCELL

El único conector de campo que todavía estaba descrito con una familia no inequívoca era `J_LOADCELL`.

PR #16 lo migra a:

- fabricante: Phoenix Contact;
- MPN: **1757268**;
- modelo: `MSTBA 2,5/4-G-5,08`;
- 4 posiciones;
- pitch 5.08 mm;
- footprint: `Connector_Phoenix_MSTB:PhoenixContact_MSTBA_2,5_4-G-5,08_1x04_P5.08mm_Horizontal`.

Así todas las interfaces FIELD I/O poseen un footprint/MPN suficientemente definido para iniciar placement.

## 6. Reglas de proximidad

PR #17 deberá colocar:

- protección ESD inmediatamente detrás de conectores de campo;
- pH/ORP/TEMP/DO y sus redes únicamente en Z1;
- HX711/load-cell del lado Z1 de Z2;
- HMI del lado Z3 de Z2;
- conector de 12 V + TVS + eFuse como cluster Z3;
- TPSM33625 con su switching loop confinado a Z3;
- drivers de bomba/solenoide y bulk local en Z4, próximos a sus salidas;
- `PUMP_CURRENT_ADC` alejado de nodos switching;
- retornos high-current sin atravesar Z1/Z2;
- PhotoMOS/chiller como contacto seco **SELV ≤48 V / NO MAINS**.

## 7. Qué permanece deliberadamente abierto

No son blockers de placement inicial:

- ancho final del PCB: 220 mm sigue provisional hasta medir courtyards reales;
- exact antenna-local clearance: no publicado en el texto oficial revisado y no se inventará;
- enclosure/3D RF validation;
- termografía/HIL;
- pre-scan EMC;
- routing.

Si el placement real exige más ancho, PR #17 podrá crecer exclusivamente hacia `+X`, manteniendo Z0 inmutable y el orden Z0→Z1→Z2→Z3→Z4.

## 8. Criterio de salida

PR #16 puede considerarse cerrado cuando:

- snapshot oficial Arduino está registrado;
- J_LOADCELL está migrado a Phoenix 1757268 en JSON+BOM+KiCad;
- hierarchy completo continúa `ERC=0/0`;
- auditoría crítica PR #13 permanece cerrada;
- los 12 FIELD I/O coinciden con sus footprints contractuales;
- `.kicad_pcb` sigue con **0 production placements**;
- routing continúa en cero;
- readiness CI queda verde.

Después de ese gate, **PR #17 puede iniciar placement XY real, pero no routing**.

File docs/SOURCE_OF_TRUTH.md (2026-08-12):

# NFB Insight PCBA v2 — Jerarquía de Fuentes de Verdad

## Regla obligatoria para Arduino UNO Q

Para cualquier decisión que dependa del **Arduino UNO Q**, la fuente primaria de verdad se consulta en los repositorios oficiales de Arduino en GitHub antes de congelar arquitectura, esquemático, PCB, firmware o documentación.

### Prioridad 1 — GitHub oficial Arduino

- Organización: `https://github.com/Arduino`
- Repositorios: `https://github.com/orgs/arduino/repositories`
- En particular, cuando aplique:
  - `arduino/docs-content`
  - `arduino/linux-qcom`
  - repositorios oficiales de App Lab, Bridge, cores, ejemplos o hardware publicados por Arduino.

Para UNO Q, `arduino/docs-content` contiene actualmente la documentación fuente de:

- datasheet `ABX00162-ABX00173`;
- especificación detallada de potencia;
- especificaciones técnicas;
- documentación de carriers oficiales como UNO Breakout Carrier.

### Prioridad 2 — Documentación oficial Arduino

- `https://docs.arduino.cc/hardware/uno-q/`
- `https://docs.arduino.cc/certifications/`
- PDFs oficiales de schematic, datasheet, STEP y pinout publicados por Arduino.

La documentación web/PDF se usa como confirmación y como artefacto de expediente, pero si existe una versión fuente más reciente en repos oficiales, el repositorio oficial se revisa primero.

### Prioridad 3 — Fabricante del componente

Para componentes que **no son Arduino UNO Q**, la fuente primaria es el fabricante original: TI, Honeywell, Nexperia, DFRobot, Phoenix Contact, Littelfuse y el fabricante del MPN correspondiente. Se priorizan datasheets, product pages, PCN/EOL, modelos CAD y documentación de calidad/RoHS/REACH.

### Prioridad 4 — Fuentes secundarias

Distribuidores, foros, blogs, repositorios de terceros y documentos históricos pueden orientar una investigación, pero **no congelan una decisión de producción** cuando existe una fuente primaria disponible.

## Regla de conflicto

Si dos fuentes oficiales parecen contradecirse:

1. revisar fecha/commit/revisión;
2. preferir la fuente oficial más reciente y específica;
3. inspeccionar schematic/CAD oficial cuando la documentación textual no resuelva el punto;
4. registrar la divergencia en el PR;
5. no congelar fabricación hasta resolverla.

## Aplicación a PR #9

La revisión de `arduino/docs-content` corrigió una interpretación previa del pin de 5 V del UNO Q: Arduino documenta oficialmente que el pin de 5 V de JANALOG puede recibir **5 V regulados** para alimentar el host, además de USB-C 5 V y VIN 7–24 V.

NFB Insight V2 mantiene, sin embargo, **12 V protegido → VIN** como método preferido y conserva `5V_RAIL` / `3V3_RAIL` del shield separados. Esa separación es una **decisión de arquitectura NFB**, no una limitación atribuida al UNO Q.

## Snapshot oficial aplicado a PR #16 — pre-placement

Antes de autorizar coordenadas XY de producción se revalidó `arduino/docs-content` en el commit:

`24445a32e249d410c1e4359bdc99d8c0dcb17bd2`

Archivos primarios revisados:

- `content/hardware/02.uno/boards/uno-q/product.md`
- `content/hardware/02.uno/boards/uno-q/datasheet/datasheet.md`
- `content/hardware/02.uno/boards/uno-q/tech-specs.yml`

La revisión confirma para los SKU ABX00162/ABX00173:

- módulo wireless `WCBN3536A`, basado en Qualcomm `WCN3980`;
- Wi‑Fi/Bluetooth con **shared PCB antenna** en el UNO Q;
- soporte oficial para expansión mediante shields/carriers;
- evidencia de certificaciones del host que incluye CE/RED, RoHS, REACH y WEEE.

### Regla RF derivada para NFB

En los archivos fuente de Arduino revisados **no se encontró una dimensión textual oficial para un antenna keepout numérico**. Por tanto:

- NFB **no inventa** una distancia/rectángulo RF atribuido a Arduino;
- ningún footprint de producción NFB se coloca dentro del envelope físico Z0 del UNO Q;
- la extensión del shield comienza en `X=53.34 mm`;
- Z1, inmediatamente adyacente, permanece como zona de sensores/quiet;
- Z3 y Z4, donde viven switching/high-current, continúan desplazadas hacia +X;
- cualquier metal, shield, bracket, PCB apilada o elemento de enclosure sobre la región RF del host queda sujeto a revisión 3D/RF posterior.

Las separaciones resultantes entre el borde +X del host y los guides Z3/Z4 son **consecuencia de la arquitectura NFB**, no especificaciones de antenna clearance de Arduino.

## Gate de ingeniería

Los PR que modifiquen interfaces del UNO Q deben:

- citar o registrar la fuente oficial Arduino revisada;
- actualizar contratos machine-readable si cambia una interpretación;
- actualizar `README.md` cuando cambie arquitectura/estado;
- mantener CI consistente con la fuente de verdad vigente.

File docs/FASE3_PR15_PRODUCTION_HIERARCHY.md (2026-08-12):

# Fase 3 — PR #15: materialización EDA de producción Z0–Z4

**Estado:** baseline propuesto para merge  
**Fecha:** 2026-08-12  
**Objetivo:** convertir la jerarquía inter-zona de PR #14 en una representación KiCad completa y reproducible de las referencias, pines, nets y footprints de producción, sin habilitar todavía placement ni routing.

## 1. Resultado

PR #15 elimina la deuda ERC deliberada de PR #14. Las cinco hojas del root contienen ahora representación interna de producción:

- Z0 → Arduino UNO Q host desde `hardware/insight_pin_contract.json`;
- Z1 → sensores desde `hardware/z1_production_netlist.json` + BOM Z1;
- Z2 → digital/bajo ruido desde `hardware/z2_production_netlist.json` + BOM Z2;
- Z3 → potencia desde `hardware/power_production_netlist.json` + BOM de potencia;
- Z4 → actuadores desde `hardware/z4_production_netlist.json` + BOM Z4.

El root continúa siendo `kicad/NFB_Insight_PCBA_v2.kicad_sch` y conserva las fronteras inter-zona congeladas en PR #14.

## 2. Fuente de verdad y generación

No se transcriben manualmente más de cien referencias a KiCad.

Flujo reproducible:

```text
JSON de producción + BOM
        ↓
tools/generate_production_schematics.py
        ↓
representación raw de refs / pins / nets / footprints
        ↓
tools/normalize_pr15_schematics.py
        ↓
child sheets Z0–Z4 + librería NFB_GEN
        ↓
KiCad 10.0.5 root ERC
```

`generate_production_schematics.py` exige antes de generar:

- igualdad exacta de referencias BOM ↔ JSON;
- igualdad de footprints BOM ↔ JSON;
- coherencia pin ↔ net dentro de cada contrato;
- endpoints externos/inter-zona válidos;
- 32 pads del UNO Q derivados del pin contract.

`normalize_pr15_schematics.py --check` exige que los archivos versionados puedan reproducirse byte-for-byte desde esas fuentes.

**Regla:** los child sheets generados no se editan manualmente para cambiar conectividad. El cambio se hace primero en el contrato JSON/BOM y luego se regenera.

## 3. Símbolos NFB_GEN

Los símbolos `NFB_GEN` son carriers EDA neutrales generados. Conservan:

- referencia;
- value;
- MPN;
- footprint;
- número de pin;
- nombre de net;
- estado DNP cuando aplica.

Los pines generados se modelan como `passive` o `no_connect`. Esto es deliberado: los JSON congelados describen topología, pero no contienen una taxonomía completa de tipos eléctricos de pin equivalente a una librería KiCad nativa. PR #15 no inventa esa semántica para fabricar un ERC artificialmente sofisticado.

Por tanto, el **ERC=0 de PR #15 certifica la integridad de la jerarquía materializada, ausencia de dangling nets y resolución de footprints**, mientras la intención eléctrica de cada bloque continúa protegida por los contratos/netlists y sus validadores especializados de Z1, Z2, potencia y Z4.

## 4. Alcance de labels

PR #14 utilizaba hojas de interfaz sin componentes internos y tenía 125 `label_dangling` controlados.

PR #15:

- mantiene `hierarchical_label` exclusivamente en las fronteras de cada child sheet;
- usa labels locales para unir componentes dentro de una misma hoja;
- elimina contaminación de alcance por `global_label` internos;
- registra la librería de proyecto `NFB_GEN` en `kicad/sym-lib-table`.

## 5. Correcciones de footprints detectadas durante la materialización

La ejecución real de KiCad 10.0.5 permitió detectar asignaciones antiguas o inexistentes antes de placement.

### 5.1 TXU0202DCUR

`U_HMI_LVL` cambia a:

```text
NFB:TI_DCU0008A_TXU0202
```

La huella local reproduce el land pattern del package TI `DCU0008A` usado por `TXU0202DCUR`: 8 pads, pad nominal 0.85 × 0.30 mm, pitch 0.50 mm y separación de centros entre columnas de pads de 3.10 mm.

Fuente primaria: Texas Instruments, package drawing `DCU0008A / 4225266` del encapsulado DCU de TXU0202.

### 5.2 Phoenix Contact 1757242

`J_PWR_IN`, `J_PUMP`, `J_CO2_SOL` y `J_CHILLER_CTL` quedan asignados a:

```text
Connector_Phoenix_MSTB:PhoenixContact_MSTBA_2,5_2-G-5,08_1x02_P5.08mm_Horizontal
```

El MPN `1757242` corresponde oficialmente a `MSTBA 2,5/ 2-G-5,08`, 2 posiciones, una fila y pitch 5.08 mm.

Fuente primaria: Phoenix Contact, producto `1757242`.

### 5.3 Littelfuse 045401.5MR

`F_ACT` queda asignado a:

```text
NFB:Littelfuse_0454_NANO2
```

Littelfuse identifica `045401.5MR` como fusible NANO² Slo-Blo, serie 454, 1.5 A, y publica para esta familia el recurso oficial **Fuse 452 and 454 Datasheet**.

La huella NFB congela el land pattern 452/454 utilizado para este MPN: cuerpo nominal 6.10 × 2.69 mm; span exterior recomendado 6.86 mm; gap interior 2.95 mm; ancho de land 3.15 mm; longitud de copper land derivada `(6.86 - 2.95)/2 = 1.955 mm`.

Fuente primaria: Littelfuse, serie 454 / `045401.5MR`, datasheet conjunto 452/454.

## 6. ERC PR #15

Evidencia en GitHub Actions con `kicad/kicad:10.0.5`:

```text
Found 0 violations
ERC messages: 0
Errors: 0
Warnings: 0
```

El contrato `hardware/root_eda_contract.json` pasa a schema 3 y establece:

```text
ZERO_VIOLATIONS_REQUIRED_PR15
```

El workflow root ejecuta KiCad con `--severity-all --exit-code-violations`; cualquier nuevo error o warning vuelve a bloquear el merge.

## 7. Fronteras preservadas

PR #15 no cambia:

- GND común Z0–Z4;
- rails `3V3_RAIL` / `5V_RAIL` locales del shield, excluyendo Z0;
- I²C compartido Z0/Z1/Z2;
- `12V_ACT` Z3/Z4;
- A4 = `PUMP_CURRENT_ADC`;
- D10 = `ACT_FAULT_N`;
- prohibición de `CO2_ADC`, `TEMP_ADC`, `HUM_ADC`, `CO2_PWM`, `CO2_FLOW_PWM` y RS485 Insight activo.

## 8. Lo que PR #15 NO autoriza

- no placement XY de componentes de producción;
- no routing;
- no cambio de `Edge.Cuts` ni del ancho provisional de 220 mm;
- no relajación de ERC;
- no sustitución silenciosa de MPN o footprint;
- no cambio de pinout del UNO Q.

El `.kicad_pcb` debe continuar con el UNO Q mecánico y **cero referencias de producción Z1–Z4 colocadas**.

## 9. Gate siguiente

Antes de iniciar placement físico deben cerrarse dos tareas de pre-placement:

1. keepouts mecánicos/RF definitivos del UNO Q y enclosure;
2. auditoría de cualquier footprint restante cuyo riesgo físico justifique revisión antes de asignar coordenadas XY.

Solo después se habilita Fase 4: placement Z0→Z4, conectores de campo hacia `Y=0/-Y`, separación limpio/sucio, revisión 3D y congelación del ancho real de la PCBA.

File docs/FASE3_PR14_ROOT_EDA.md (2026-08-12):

# PR #14 — Integración EDA raíz Z0–Z4

**Estado:** jerarquía eléctrica inter-zona previa a materialización completa de símbolos internos.  
**Fuente machine-readable:** `hardware/root_eda_contract.json`.  
**Root KiCad:** `kicad/NFB_Insight_PCBA_v2.kicad_sch`.

## Objetivo

Sustituir el antiguo root textual/Z1 por una jerarquía KiCad que conecte las fronteras eléctricas entre:

- Z0 — Arduino UNO Q host;
- Z1 — sensores;
- Z2 — digital / bajo ruido;
- Z3 — potencia;
- Z4 — actuadores.

PR #14 **no pretende todavía dibujar de nuevo cada componente interno** de las cuatro zonas. La conectividad interna continúa gobernada por los netlists JSON/BOM de producción ya validados. Esto evita duplicar manualmente más de cien referencias y crear una segunda fuente de verdad antes de construir un generador reproducible.

## Jerarquía

El root instancia cinco hojas:

- `uno_q_interface.kicad_sch`
- `z1_interface.kicad_sch`
- `z2_interface.kicad_sch`
- `z3_interface.kicad_sch`
- `z4_interface.kicad_sch`

Cada hoja expone `hierarchical_label` y el root contiene el `sheet pin` correspondiente conectado mediante la net local del mismo nombre.

## Frontera UNO Q

Z0 expone únicamente endpoints activos del contrato `hardware/insight_pin_contract.json`.

Puntos críticos:

- `GND` sí pertenece a Z0 y es referencia común Z0–Z4.
- `3V3_RAIL` y `5V_RAIL` **no pertenecen a Z0**; siguen siendo rails locales del shield.
- `J_UNOQ.4` no alimenta `3V3_RAIL`.
- `J_UNOQ.5` no alimenta `5V_RAIL`.
- `UNO_IOREF_3V3` es host→shield.
- `12V_HOST_VIN` es shield→VIN del host.
- A4=`PUMP_CURRENT_ADC`; D10=`ACT_FAULT_N`.
- `CO2_ADC`, `TEMP_ADC`, `HUM_ADC`, `CO2_PWM/CO2_FLOW_PWM` y RS485 Insight permanecen prohibidos.

## Nets inter-zona

`hardware/root_eda_contract.json` congela la pertenencia de cada net. Ejemplos:

- `GND`: Z0/Z1/Z2/Z3/Z4.
- `5V_RAIL`: Z1/Z2/Z3.
- `3V3_RAIL`: Z1/Z2/Z3/Z4.
- I²C SDA/SCL: Z0/Z1/Z2.
- sensores analógicos/digitales: Z0↔Z1.
- HMI/HX711/watchdog/status: Z0↔Z2.
- host VIN/IOREF: Z0↔Z3.
- `12V_ACT`: Z3↔Z4.
- controles/diagnóstico de actuadores: Z0↔Z4.

## Contrato Z1 separado

El archivo raíz antiguo contenía en realidad el contrato textual Z1. PR #14 lo separa como `kicad/z1_sensor_contract.kicad_sch` para que los gates Z1 sigan validando el baseline PR #6/#12 sin confundirlo con la nueva jerarquía raíz.

## Gate automático de estructura

`tools/validate_root_eda.py` comprueba:

- exactamente cinco hojas Z0–Z4;
- endpoint set Z0 = endpoints activos del pin contract;
- GND incluye Z0 y rails locales excluyen Z0;
- labels de cada child sheet = contrato inter-zona;
- cantidad de sheet pins/labels del root = ownership contractual;
- I²C y rails compartidos correctos;
- ausencia de nets legacy/prohibidas;
- footprints PR #13 siguen cerrados;
- `.kicad_pcb` continúa sin placement de componentes de producción.

## Gate ERC transitorio y explícito

`zone_internal_component_symbols=false` significa que los endpoints de las hojas terminan de forma deliberada en labels/hierarchical labels hasta que PR #15 genere los símbolos internos. Con KiCad 10.0.5, el hierarchy PR #14 produce **exactamente 125 eventos `label_dangling`** y ningún otro tipo de violación.

Esto NO se resuelve bajando la severidad `label_dangling` ni ignorando el ERC. La política está congelada en `hardware/root_eda_contract.json` y `tools/validate_pr14_erc_report.py` exige:

- `expected_violation_type = label_dangling`;
- `expected_violation_count = 125`;
- `unexpected_violation_count_allowed = 0`;
- resumen del reporte = 125 errores / 0 warnings.

Si cambia el número o aparece otra categoría ERC, CI falla. Así, PR #14 mantiene una deuda técnica **acotada, reproducible y visible** exclusivamente porque faltan símbolos internos.
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

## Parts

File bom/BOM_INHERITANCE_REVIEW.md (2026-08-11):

# NFB Insight PCBA v2 — Revisión de Herencia de BOM

Este archivo registra qué componentes del diseño donante pueden heredarse al arranque de la V2 y cuáles requieren una nueva selección o validación eléctrica/mecánica antes de congelar el esquemático.

## Leyenda de estado

- `ACEPTAR` — puede heredarse al conjunto de esquemático/footprints de la V2.
- `REVISAR` — candidato útil del diseño donante, pero selección, rating o footprint deben aprobarse nuevamente.
- `DESCARTAR` — no forma parte de la línea base Insight V2.
- `RESERVA` — capacidad futura; no debe provocar congestión en el placement de la V2.

## Potencia y protección

| Ref. donante | Parte | Valor donante | Estado V2 | Razón |
|---|---|---|---|---|
| D1 | SMAJ15A | TVS 15 V | REVISAR | El concepto de protección es útil; clamp y energía deben corresponder a la arquitectura final de 12 V. |
| F1 | MF-MSMF110/24X-2 | 1.1 A hold / 2.2 A trip | REVISAR | El rating donante es incompatible con algunos escenarios de corriente Insight documentados. Redimensionar después de congelar los dominios de corriente. |
| D2 | SS34 | Schottky 3 A | REVISAR | Un camino de 3 A puede ser insuficiente si transporta corriente de actuadores. Evaluar cambio de arquitectura antes de simplemente aumentar el diodo. |
| U1 | TPS54302DDCR | buck 12→5 V / 3 A | REVISAR | La función es adecuada; recalcular margen térmico/carga y demanda real del UNO Q/HMI. |
| L1 | 744043004700 | 4.7 µH / 4 A | REVISAR | Revalidar con el punto de operación definitivo del buck y el objetivo de ripple. |
| U2 | AMS1117-3.3 | 3.3 V / 800 mA | REVISAR | Es utilizable, pero deben considerarse eficiencia, térmica y alternativas modernas. |
| FB1 | BLM31PG601SN1L | 600 Ω @ 100 MHz / 2 A | REVISAR | Mantener solo si continúa siendo necesaria la segmentación/filtrado de rails. |

## Analógico / front-end de sensores

| Elemento donante | Estado V2 | Notas |
|---|---|---|
| Op-amps MCP6002-I/SN | ACEPTAR | Mantener para buffering de bajo voltaje cuando la interfaz final del sensor continúe requiriendo acondicionamiento analógico. |
| ESD PESD5V0 / PESD3V3 | ACEPTAR | Mantener concepto y footprints; verificar tensión de trabajo exacta por interfaz. |
| Redes RC antialias | ACEPTAR | Los valores son punto de partida; ajustar con pruebas reales de ancho de banda/ruido. |
| Front-end pH | ACEPTAR | Ubicar directamente sobre el conector PH de campo; minimizar longitud de pista de alta impedancia. |
| Front-end ORP | ACEPTAR | Misma regla de placement que pH. |
| Front-end TEMP | ACEPTAR | Mapeo fuente de verdad: A2. |
| Front-end presión CO2 | ACEPTAR | Mapeo fuente de verdad: A4. |
| Front-end DO | ACEPTAR | Mapeo fuente de verdad: A5; revalidar estrategia de aislamiento. |
| Canal analógico de humedad | DESCARTAR | A3 reservado/DNP en Insight V2. |

## Digital / interfaces

| Elemento donante | Estado V2 | Notas |
|---|---|---|
| Pull-ups I2C 4.7 kΩ | ACEPTAR | Bus D20/D21; el pull-up equivalente final deberá considerar todos los módulos conectados. |
| HX711 | ACEPTAR | Mantener como interfaz Insight para celda de carga. |
| RTC DS3231 | ACEPTAR | Mantener si sigue siendo necesario después de revisar arquitectura de firmware/sistema. |
| Ruta GPS SAM-M8Q | ACEPTAR | El placement deberá considerar antena, cobre y restricciones del enclosure. |
| Interfaz/conector HMI UART | ACEPTAR | Conector de campo sobre borde `Y=0`, orientado hacia `-Y`. |
| Concepto de watchdog externo TPS3823 | ACEPTAR | Se conserva el contrato D4 `MCU_WDI`. |
| Bridge RS485 SC16IS740 + SN74LVC1G04 | RESERVA | No permitir que la futura ruta Signature/RS485 congestione Insight salvo necesidad explícita en V2. |

## Actuadores

| Elemento donante | Estado V2 | Notas |
|---|---|---|
| Control bomba PWM/DIR | ACEPTAR | Mantener función de control; revisar etapa de potencia en zona de potencia ruidosa. |
| Control solenoide CO2 | ACEPTAR | Mantener función de control; salida de campo en `Y=0`. |
| Control chiller | ACEPTAR | Solo señal de control en línea base; la energía de alta potencia del chiller debe permanecer preferiblemente externa a la PCBA. |
| Etapa IR2104 + IRLZ44N | REVISAR | Reevaluar topología, encapsulado y carga real de bomba antes de copiar. |
| Relés HF46F | REVISAR | Definir si conmutan 12 V SELV o cargas externas/red; los clearances dependen de ello. |
| Optoacopladores PC817 | REVISAR | Mantener intención de aislamiento, pero revisar CTR, envejecimiento, velocidad y necesidad real de aislamiento por salida. |
| Ruta PWM válvula proporcional CO2 | DESCARTAR | D9 reservado/DNP en la línea base Insight V2. |

## Conectores

Los números de parte de conectores del BOM donante **no quedan congelados automáticamente** para V2. La selección deberá responder a la nueva arquitectura de enclosure y cableado.

Principio preferido para V2:

- todos los conectores cableados de campo sobre `Y=0` y orientados hacia `-Y`;
- esfuerzos mecánicos de cables pesados/coaxiales terminados en el panel del enclosure cuando sea práctico;
- familias de conectores elegidas por facilidad de servicio, polarización/keying y requisitos ambientales;
- conexiones internas cortas desde interfaces pH/ORP/DO montadas en panel hasta sus front-end analógicos.

## Antes de congelar el esquemático

1. Congelar dominios de 12 V y determinar qué cargas se alimentarán a través de la board.
2. Recalcular corriente máxima continua y de pico por dominio.
3. Seleccionar conector de entrada, protección, ancho de cobre y fusible/PTC según esas corrientes.
4. Congelar estrategia de conectores panel vs. PCBA.
5. Verificar todos los componentes aceptados contra disponibilidad y lifecycle actuales.
6. Generar BOM legible por máquina únicamente después de completar estas revisiones.

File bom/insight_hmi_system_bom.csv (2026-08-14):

categoria | item_id | qty | rol_producto | fabricante | mpn_modelo | sku | footprint_o_mecanica | poblacion_pcba | alimentacion | interfaz | fuente | nota
HMI | HMI_DISPLAY | 1 | PRODUCTION_EXTERNAL_ASSEMBLY | Nextion / ITEAD | NX8048P050-011C-Y | 6920075776553 | NFB:Nextion_NX8048P050_011C_Y_Enclosure | NO | 5V 1A | XH2.54 4P UART | https://itead.cc/product/5-0-nextion-intelligent-series-hmi-touch-display-with-enclosure/ | 5.0in capacitiva Intelligent Series con enclosure; 800x480; envelope 160.04x107.07 mm.
HMI | HMI_SD_EXT | 1 | PRODUCTION_EXTERNAL_ACCESSORY | Nextion / ITEAD | SDExtender |  | NFB:Nextion_SDExtender_External | NO | N/A | microSD FAT32 | https://itead.cc/product/nextion-micro-sd-card-extender/ | 17.1x41.48x2.5 mm; extensor microSD para acceso desde enclosure.
HMI | HMI_SPEAKER | 1 | PRODUCTION_EXTERNAL_ACCESSORY | Nextion / ITEAD | Nextion BOX Speaker |  | NFB:Nextion_BOX_Speaker_External | NO | +0.5A sobre presupuesto HMI | 1.25mm 2P female 1.25T-2-2A | https://itead.cc/product/nextion-box-speaker/ | 31x28x14.8 mm; 1.5W; cable 250mm; reservar HMI total 5V/1.5A.
SERVICE | HMI_FOCA_MAX | 1 | SERVICE_PROGRAMMING_TOOL_NOT_INSTALLED | Nextion / ITEAD | Foca Max |  | NFB:Nextion_Foca_Max_Service | NO | DC 8-26V -> 5-5.5V max 2A | USB 2.0 / TTL 3.3V CP2102 | https://itead.cc/product/nextion-foca-max-5v2a-output-usb-to-ttl-serial-converter-board/ | 50x50x12 mm; incluye USB wire y XH2.54 4P wire; programación/bring-up exclusivamente.
INTERFACE | J_HMI | 1 | PCBA_BOARD_SIDE_INTERFACE | JST | S4B-XH-A(LF)(SN) |  | Connector_JST:JST_XH_S4B-XH-A_1x04_P2.50mm_Horizontal | YES | 5V_RAIL | 5V/GND/UART | https://itead.cc/product/5-0-nextion-intelligent-series-hmi-touch-display-with-enclosure/ | Geometría de PCBA congelada post-PR19C; ITEAD publica XH2.54 4P y el mating con el arnés seleccionado debe verificarse en first article.
HMI_POWER | HMI_PWR_REG | 1 | PRODUCTION_EXTERNAL_POWER_ASSEMBLY | RECOM | R-78K5.0-2.0L |  | NFB:RECOM_R78K5_0_2_0L_External | NO | 6.5-36V -> 5V/2A, 10W | SIP3 / harness externo | https://recom-power.com/en/products/switching-regulators/switching-regulators-sip/rec-p-R-78K5.0-2.0L.html | No aislado; versión L horizontal 8.5mm; alimenta 5V_HMI.
HMI_POWER | HMI_PWR_FUSE_HOLDER | 1 | PRODUCTION_EXTERNAL_POWER_ASSEMBLY | Littelfuse | 0FHM0001ZXJ |  | INLINE HARNESS IP67 | NO | 58V max / 20A holder | MINI fuse / 14AWG leads | https://www.littelfuse.com/products/fuses-overcurrent-protection/fuse-holders-fuse-blocks-accessories/fuse-holders/in-line-fuse-holders/mini-fhm/0fhm0001zxj | Holder inline IP67 dedicado a rama 12V_HMI.
HMI_POWER | HMI_PWR_FUSE | 1 | PRODUCTION_EXTERNAL_POWER_ASSEMBLY | Littelfuse | 0997002.WXN |  | MINI blade | NO | 58VDC / 2A | MINI blade fuse | https://www.littelfuse.com/products/fuses-overcurrent-protection/fuses/automotive-fuses/blade-fuses-shunt/mini/997/0997002-wxn | Fusible 2A activo para rama HMI antes del RECOM.

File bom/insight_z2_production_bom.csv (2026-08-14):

bloque | ref | qty | funcion | valor | mpn_o_familia | footprint | poblacion | nota
I2C_GNSS_RTC | R_I2C_SDA | 1 | resistor | 4.7k 1% | CRCW04024K70FKED | Resistor_SMD:R_0402_1005Metric | POPULATE | Pull-up global I2C; reemplaza respaldos 10k DNP de Z1.
I2C_GNSS_RTC | R_I2C_SCL | 1 | resistor | 4.7k 1% | CRCW04024K70FKED | Resistor_SMD:R_0402_1005Metric | POPULATE | Pull-up global I2C; reemplaza respaldos 10k DNP de Z1.
I2C_GNSS_RTC | D_GNSS_SDA | 1 | esd | PESD3V3U1UL | PESD3V3U1UL,315 | Diode_SMD:D_SOD-882 | POPULATE | ESD single-line a GND sobre SDA externo.
I2C_GNSS_RTC | D_GNSS_SCL | 1 | esd | PESD3V3U1UL | PESD3V3U1UL,315 | Diode_SMD:D_SOD-882 | POPULATE | ESD single-line a GND sobre SCL externo.
I2C_GNSS_RTC | J_GNSS_RTC | 1 | connector | JST XH 4p side-entry | S4B-XH-A(LF)(SN) | Connector_JST:JST_XH_S4B-XH-A_1x04_P2.50mm_Horizontal | POPULATE | DFR1103 externo; XH-4 ↔ Gravity; orientar hacia -Y.
HX711 | U_HX | 1 | adc_loadcell | HX711 24-bit | HX711 / qualified source TBD | Package_SO:SOP-16_4.4x10.4mm_P1.27mm | POPULATE | Topología/footprint congelados; fuente HX711 a calificar en Fase 6.
HX711 | J_LOADCELL | 1 | connector | MSTBA 2,5/4-G-5,08 | 1757268 | Connector_Phoenix_MSTB:PhoenixContact_MSTBA_2,5_4-G-5,08_1x04_P5.08mm_Horizontal | POPULATE | E+/E-/A+/A-; Phoenix 1757268 exacto, 4 posiciones, pitch 5.08 mm; side-entry hacia -Y.
HX711 | C_HX_100N | 1 | capacitor | 100nF 25V X7R | GRM155R71E104KE14D | Capacitor_SMD:C_0402_1005Metric | POPULATE
HX711 | C_HX_10U | 1 | capacitor | 10uF 10V X5R | GRM21BR61A106KE19L | Capacitor_SMD:C_0805_2012Metric | POPULATE
HX711 | C_HX_VBG | 1 | capacitor | 100nF 25V X7R | GRM155R71E104KE14D | Capacitor_SMD:C_0402_1005Metric | POPULATE
HMI | J_HMI | 1 | connector | JST XH 4p side-entry | S4B-XH-A(LF)(SN) | Connector_JST:JST_XH_S4B-XH-A_1x04_P2.50mm_Horizontal | POPULATE | 5V_HMI/GND/RX/TX; side-entry -Y. 5V_HMI proviene del subensamble externo RECOM; display/audio NO cargan 5V_RAIL.
HMI | U_HMI_LVL | 1 | level_translator | TXU0202 | TXU0202DCUR | NFB:TI_DCU0008A_TXU0202 | POPULATE | TXU0202: VCCA=3V3_RAIL, VCCB=5V_HMI dedicado; UART D0/D1 preservado.
HMI | C_HMI_A | 1 | capacitor | 100nF 25V X7R | GRM155R71E104KE14D | Capacitor_SMD:C_0402_1005Metric | POPULATE
HMI | C_HMI_B | 1 | capacitor | 100nF 25V X7R | GRM155R71E104KE14D | Capacitor_SMD:C_0402_1005Metric | POPULATE | Desacoplo VCCB del TXU0202 sobre 5V_HMI dedicado.
HMI | D_HMI_RX | 1 | esd | PESD5V0U1UL | PESD5V0U1UL,315 | Diode_SMD:D_SOD-882 | POPULATE | ESD 5V single-line a GND en lado de campo.
HMI | D_HMI_TX | 1 | esd | PESD5V0U1UL | PESD5V0U1UL,315 | Diode_SMD:D_SOD-882 | POPULATE | ESD 5V single-line a GND en lado de campo.
WATCHDOG | U_WDT | 1 | supervisor_watchdog | TPS3823-30 1.6s | TPS3823-30DBVR | Package_TO_SOT_SMD:SOT-23-5 | POPULATE | Watchdog 1.6s; firmware alimenta WDI cada 400ms.
WATCHDOG | R_WDT_MR | 1 | resistor | 10k 1% | CRCW040210K0FKED | Resistor_SMD:R_0402_1005Metric | POPULATE
WATCHDOG | C_WDT | 1 | capacitor | 100nF 25V X7R | GRM155R71E104KE14D | Capacitor_SMD:C_0402_1005Metric | POPULATE
BRINGUP | TP_3V3 | 1 | testpoint | PCB test point | PCB_FEATURE | TestPoint:TestPoint_Pad_D1.0mm | PCB_FEATURE | Punto de prueba.
BRINGUP | TP_5V | 1 | testpoint | PCB test point | PCB_FEATURE | TestPoint:TestPoint_Pad_D1.0mm | PCB_FEATURE | Punto de prueba.
BRINGUP | TP_GND | 1 | testpoint | PCB test point | PCB_FEATURE | TestPoint:TestPoint_Pad_D1.0mm | PCB_FEATURE | Punto de prueba.
BRINGUP | TP_I2C_SDA | 1 | testpoint | PCB test point | PCB_FEATURE | TestPoint:TestPoint_Pad_D1.0mm | PCB_FEATURE | Punto de prueba.
BRINGUP | TP_I2C_SCL | 1 | testpoint | PCB test point | PCB_FEATURE | TestPoint:TestPoint_Pad_D1.0mm | PCB_FEATURE | Punto de prueba.
HX711 | TP_HX_DOUT | 1 | testpoint | PCB test point | PCB_FEATURE | TestPoint:TestPoint_Pad_D1.0mm | PCB_FEATURE | Punto de prueba.
HX711 | TP_HX_SCK | 1 | testpoint | PCB test point | PCB_FEATURE | TestPoint:TestPoint_Pad_D1.0mm | PCB_FEATURE | Punto de prueba.
HX711 | TP_LOAD_A_POS | 1 | testpoint | PCB test point | PCB_FEATURE | TestPoint:TestPoint_Pad_D1.0mm | PCB_FEATURE | Punto de prueba.
HX711 | TP_LOAD_A_NEG | 1 | testpoint | PCB test point | PCB_FEATURE | TestPoint:TestPoint_Pad_D1.0mm | PCB_FEATURE | Punto de prueba.
HMI | TP_HMI_TX | 1 | testpoint | PCB test point | PCB_FEATURE | TestPoint:TestPoint_Pad_D1.0mm | PCB_FEATURE | Punto de prueba.
HMI | TP_HMI_RX | 1 | testpoint | PCB test point | PCB_FEATURE | TestPoint:TestPoint_Pad_D1.0mm | PCB_FEATURE | Punto de prueba.
WATCHDOG | TP_WDI | 1 | testpoint | PCB test point | PCB_FEATURE | TestPoint:TestPoint_Pad_D1.0mm | PCB_FEATURE | Punto de prueba.
WATCHDOG | TP_NRST | 1 | testpoint | PCB test point | PCB_FEATURE | TestPoint:TestPoint_Pad_D1.0mm | PCB_FEATURE | Punto de prueba.
WATCHDOG | TP_WDT_MR | 1 | testpoint | PCB test point | PCB_FEATURE | TestPoint:TestPoint_Pad_D1.0mm | PCB_FEATURE | Punto de prueba.
BRINGUP | TP_LED_STATUS | 1 | testpoint | PCB test point | PCB_FEATURE | TestPoint:TestPoint_Pad_D1.0mm | PCB_FEATURE | Punto de prueba.

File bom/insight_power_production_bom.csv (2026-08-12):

bloque | ref | qty | funcion | valor | mpn_o_familia | footprint | poblacion | nota
ENTRADA_PROTECCION | J_PWR_IN | 1 | connector | MSTBA 2,5/2-G-5,08 | 1757242 | Connector_Phoenix_MSTB:PhoenixContact_MSTBA_2,5_2-G-5,08_1x02_P5.08mm_Horizontal | POPULATE | Phoenix Contact 5.08 mm; 12 A nominal; orientar hacia -Y en placement.
ENTRADA_PROTECCION | D_IN_TVS | 1 | tvs | SMBJ15A 600W 15V uni | SMBJ15A-TR | Diode_SMD:D_SMB | POPULATE | TVS unidireccional baseline para 12 VDC; validar surge en pre-compliance.
ENTRADA_PROTECCION | C_IN_HF | 1 | capacitor | 100nF 50V X7R | C1608X7R1H104K080AA | Capacitor_SMD:C_0603_1608Metric | POPULATE | Bypass HF adyacente al conector/eFuse.
ENTRADA_PROTECCION | U_EFUSE | 1 | efuse | TPS259470A | TPS259470ARPWR | NFB:TI_RPW0010A_TPS259470A | POPULATE | RPW0010A HotRod cerrado PR13 contra TI MPQF568/4225183-A; 10 pads lógicos con lands L en 1/4/7/10.
ENTRADA_PROTECCION | R_UVOV_R1 | 1 | resistor | 470k 1% | Vishay CRCW0402 / 470k / 1% | Resistor_SMD:R_0402_1005Metric | POPULATE | Ladder TI: VIN→R1→EN/UVLO.
ENTRADA_PROTECCION | R_UVOV_R2 | 1 | resistor | 11k 1% | Vishay CRCW0402 / 11k / 1% | Resistor_SMD:R_0402_1005Metric | POPULATE | Ladder TI: EN/UVLO→R2→OVLO.
ENTRADA_PROTECCION | R_UVOV_R3 | 1 | resistor | 47k 1% | Vishay CRCW0402 / 47k / 1% | Resistor_SMD:R_0402_1005Metric | POPULATE | Ladder TI: OVLO→R3→GND.
ENTRADA_PROTECCION | R_EFUSE_ILIM | 1 | resistor | 750R 1% | Vishay CRCW0402 / 750R / 1% | Resistor_SMD:R_0402_1005Metric | POPULATE | 750R conserva condición UL2367 publicada por TI y fija ~4.45 A typ.
ENTRADA_PROTECCION | C_EFUSE_DVDT | 1 | capacitor | 3.3nF 50V X7R | GRM155R71H332KA01D / qualified equivalent | Capacitor_SMD:C_0402_1005Metric | POPULATE | 3.3 nF baseline de slew/inrush; MPN exacto a confirmar en liberación BOM.
ENTRADA_PROTECCION | C_EFUSE_ITIMER | 1 | capacitor | 2.2nF 50V X7R | GRM155R71H222KA01D | Capacitor_SMD:C_0402_1005Metric | POPULATE | 2.2 nF baseline de transient blanking.
ENTRADA_PROTECCION | C_IN_BULK | 1 | capacitor | 100uF 25V | EEEFK1E101P | Capacitor_SMD:CP_Elec_8x6.2 | POPULATE | Bulk después del eFuse, antes del split estrella.
SPLIT_ESTRELLA | NT_HOST | 1 | net_tie | NET_TIE_2 | PCB_FEATURE | NetTie:NetTie-2_SMD_Pad0.5mm | PCB_FEATURE | Net-tie físico para estrella 12V_PROTECTED→12V_HOST_VIN.
SPLIT_ESTRELLA | NT_LOGIC | 1 | net_tie | NET_TIE_2 | PCB_FEATURE | NetTie:NetTie-2_SMD_Pad0.5mm | PCB_FEATURE | Net-tie físico para estrella 12V_PROTECTED→12V_LOGIC.
SPLIT_ESTRELLA | F_ACT | 1 | fuse | 1.5A 125V Slo-Blo Nano2 | 045401.5MR | NFB:Littelfuse_0454_NANO2 | POPULATE | 1.5 A Slo-Blo; validar inrush real pump+solenoide en HIL.
BUCK_5V | U_5V | 1 | buck_module | TPSM33625 5V/2.5A | TPSM33625RDNR | NFB:TI_RDN0011A_TPSM33625 | POPULATE | RDN0011A cerrado PR13 contra TI qfnd871/4226623-F; SMD mask preferida y stencil 0.125 mm.
BUCK_5V | R_5V_EN_PD | 1 | resistor | 100k 1% | Vishay CRCW0402 / 100k / 1% | Resistor_SMD:R_0402_1005Metric | POPULATE | Mantiene EN bajo con UNO Q/IOREF ausente.
BUCK_5V | C_5V_IN_4U7 | 1 | capacitor | 4.7uF 50V X7R | C3225X7R1H475K250AB | Capacitor_SMD:C_1210_3225Metric | POPULATE | Capacitor de entrada principal del TPSM.
BUCK_5V | C_5V_IN_100N | 1 | capacitor | 100nF 50V X7R | C1608X7R1H104K080AA | Capacitor_SMD:C_0603_1608Metric | POPULATE | Bypass HF del TPSM.
BUCK_5V | R_5V_FBT | 1 | resistor | 40.2k 1% | Vishay CRCW0402 / 40.2k / 1% | Resistor_SMD:R_0402_1005Metric | POPULATE | Feedback superior para 5.0 V.
BUCK_5V | R_5V_FBB | 1 | resistor | 10k 1% | Vishay CRCW0402 / 10k / 1% | Resistor_SMD:R_0402_1005Metric | POPULATE | Feedback inferior 10 kΩ.
BUCK_5V | C_5V_VCC | 1 | capacitor | 1uF 25V X7R | GRM188R71E105KA12D | Capacitor_SMD:C_0603_1608Metric | POPULATE | Capacitor obligatorio VCC del TPSM.
BUCK_5V | C_5V_OUT1 | 1 | capacitor | 22uF 16V X7R | GCM32ER71C226ME19L | Capacitor_SMD:C_1210_3225Metric | POPULATE | 22uF nominal; validar DC-bias; total efectivo de salida >=25uF.
BUCK_5V | C_5V_OUT2 | 1 | capacitor | 22uF 16V X7R | GCM32ER71C226ME19L | Capacitor_SMD:C_1210_3225Metric | POPULATE | 22uF nominal; validar DC-bias; total efectivo de salida >=25uF.
BUCK_5V | C_5V_HF | 1 | capacitor | 100nF 25V X7R | GRM155R71E104KE14D | Capacitor_SMD:C_0402_1005Metric | POPULATE | Bypass HF del rail 5V.
BUCK_5V | R_5V_PG_PU | 1 | resistor | 47k 1% | Vishay CRCW0402 / 47k / 1% | Resistor_SMD:R_0402_1005Metric | POPULATE | Pull-up PGOOD a 5V_RAIL; habilita LDO 3V3.
LDO_3V3 | U_3V3 | 1 | ldo | TLV75533 3.3V/500mA | TLV75533PDBVR | Package_TO_SOT_SMD:SOT-23-5 | POPULATE | SOT-23-5; EN=5V_PGOOD.
LDO_3V3 | C_3V3_IN | 1 | capacitor | 1uF 25V X7R | GRM188R71E105KA12D | Capacitor_SMD:C_0603_1608Metric | POPULATE | Entrada LDO >=1uF nominal.
LDO_3V3 | C_3V3_OUT | 1 | capacitor | 1uF 25V X7R | GRM188R71E105KA12D | Capacitor_SMD:C_0603_1608Metric | POPULATE | Salida LDO >=1uF nominal.
LDO_3V3 | C_3V3_HF | 1 | capacitor | 100nF 25V X7R | GRM155R71E104KE14D | Capacitor_SMD:C_0402_1005Metric | POPULATE | Bypass HF local 3V3.
TESTPOINT | TP_12V_RAW | 1 | testpoint | PCB test point | PCB_FEATURE | TestPoint:TestPoint_Pad_D1.0mm | PCB_FEATURE | Bring-up antes de protección.
TESTPOINT | TP_12V_PROT | 1 | testpoint | PCB test point | PCB_FEATURE | TestPoint:TestPoint_Pad_D1.0mm | PCB_FEATURE | Bring-up después de eFuse.
TESTPOINT | TP_12V_LOGIC | 1 | testpoint | PCB test point | PCB_FEATURE | TestPoint:TestPoint_Pad_D1.0mm | PCB_FEATURE | Bring-up rama limpia.
TESTPOINT | TP_12V_ACT | 1 | testpoint | PCB test point | PCB_FEATURE | TestPoint:TestPoint_Pad_D1.0mm | PCB_FEATURE | Bring-up rama actuadores.
TESTPOINT | TP_5V_PGOOD | 1 | testpoint | PCB test point | PCB_FEATURE | TestPoint:TestPoint_Pad_D1.0mm | PCB_FEATURE | Verificar secuencia host→5V→3V3.

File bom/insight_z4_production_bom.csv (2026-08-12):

bloque | ref | qty | funcion | valor | mpn_o_familia | footprint | poblacion | nota
PUMP | U_PUMP_DRV | 1 | hbridge | DRV8242H-Q1 | DRV8242HQRHLRQ1 | NFB:TI_RHL0020B_DRV8242 | POPULATE | Automotive H-bridge HW; PH/EN; footprint RHL0020B cerrado PR13 contra drawing TI 4226154/B.
PUMP | R_PUMP_SR | 1 | resistor | 22k 1% | CRCW040222K0FKED | Resistor_SMD:R_0402_1005Metric | POPULATE | SR LVL3 ~15-17 V/us para compromiso EMC.
PUMP | C_PUMP_VM | 1 | capacitor | 100nF 50V X7R | C1608X7R1H104K080AA | Capacitor_SMD:C_0603_1608Metric | POPULATE | Bypass VM local obligatorio TI.
PUMP | C_PUMP_BULK | 1 | capacitor | 22uF 25V X7R | GRM32ER71E226KE15L | Capacitor_SMD:C_1210_3225Metric | POPULATE | Bulk local >=10uF efectivo cerca VM; validar DC bias.
PUMP | R_PUMP_PWM_SER | 1 | resistor | 100R 1% | CRCW0402100RFKED | Resistor_SMD:R_0402_1005Metric | POPULATE | Serie D5->EN para limitar edge/ringing.
PUMP | R_PUMP_PWM_PD | 1 | resistor | 100k 1% | CRCW0402100KFKED | Resistor_SMD:R_0402_1005Metric | POPULATE | Fail-safe PWM bajo durante arranque.
PUMP | R_PUMP_DIR_SER | 1 | resistor | 100R 1% | CRCW0402100RFKED | Resistor_SMD:R_0402_1005Metric | POPULATE | Serie D6->PH.
PUMP | R_PUMP_DIR_PD | 1 | resistor | 100k 1% | CRCW0402100KFKED | Resistor_SMD:R_0402_1005Metric | POPULATE | Dirección definida durante arranque.
PUMP | R_PUMP_IPROPI | 1 | resistor | 1.5k 1% | CRCW04021K50FKED | Resistor_SMD:R_0402_1005Metric | POPULATE | Convierte IPROPI a PUMP_CURRENT_ADC A4; margen ADC >2.7A worst-scale.
PUMP | C_PUMP_IPROPI | 1 | capacitor | 100nF | GRM155R71E104KE14D | Capacitor_SMD:C_0402_1005Metric | POPULATE | Filtrado de telemetría corriente.
PUMP | J_PUMP | 1 | connector | MSTBA 2.5/2-G-5.08 | 1757242 | Connector_Phoenix_MSTB:PhoenixContact_MSTBA_2,5_2-G-5,08_1x02_P5.08mm_Horizontal | POPULATE | Salida bomba OUT1/OUT2; orientar -Y.
PUMP | TP_PUMP_CURRENT | 1 | testpoint | PUMP_CURRENT_ADC | PCB_FEATURE | TestPoint:TestPoint_Pad_D1.0mm | PCB_FEATURE | Bring-up corriente bomba.
PUMP | TP_PUMP_OUT1 | 1 | testpoint | PUMP_OUT1 | PCB_FEATURE | TestPoint:TestPoint_Pad_D1.5mm | PCB_FEATURE | Bring-up potencia.
PUMP | TP_PUMP_OUT2 | 1 | testpoint | PUMP_OUT2 | PCB_FEATURE | TestPoint:TestPoint_Pad_D1.5mm | PCB_FEATURE | Bring-up potencia.
CO2_SOL | U_CO2_DRV | 1 | smart_high_side | TPS1HC120C-Q1 | TPS1HC120CQDYCRQ1 | NFB:TI_DYC0008A_TPS1HC120 | POPULATE | DYC0008A cerrado PR13 contra TI 4226548/B; exactamente 8 pads y sin PowerPAD.
CO2_SOL | R_CO2_ILIM | 1 | resistor | 27k 1% | CRCW040227K0FKED | Resistor_SMD:R_0402_1005Metric | POPULATE | TI formula 13.5/Rk -> ~0.5A limit.
CO2_SOL | C_CO2_DRV | 1 | capacitor | 100nF 50V X7R | C1608X7R1H104K080AA | Capacitor_SMD:C_0603_1608Metric | POPULATE | Bypass VBB local.
CO2_SOL | R_CO2_EN_SER | 1 | resistor | 100R 1% | CRCW0402100RFKED | Resistor_SMD:R_0402_1005Metric | POPULATE | Serie D7->EN.
CO2_SOL | R_CO2_EN_PD | 1 | resistor | 100k 1% | CRCW0402100KFKED | Resistor_SMD:R_0402_1005Metric | POPULATE | Fail-safe válvula cerrada en arranque.
CO2_SOL | R_CO2_OPENLOAD_PU | 1 | resistor | 10k 1% | CRCW040210K0FKED | Resistor_SMD:R_0402_1005Metric | POPULATE | Pull-up FLT2/open-load local.
CO2_SOL | TP_CO2_OPENLOAD | 1 | testpoint | CO2_OPENLOAD_N | PCB_FEATURE | TestPoint:TestPoint_Pad_D1.0mm | PCB_FEATURE | Diagnóstico bring-up.
CO2_SOL | J_CO2_SOL | 1 | connector | MSTBA 2.5/2-G-5.08 | 1757242 | Connector_Phoenix_MSTB:PhoenixContact_MSTBA_2,5_2-G-5,08_1x02_P5.08mm_Horizontal | POPULATE | Salida +12V conmutada y GND; orientar -Y.
CO2_SOL | TP_CO2_SOL_POS | 1 | testpoint | CO2_SOL_POS | PCB_FEATURE | TestPoint:TestPoint_Pad_D1.5mm | PCB_FEATURE | Bring-up salida solenoide.
CHILLER | U_CHILLER | 1 | photomos | GE DIP4 1 Form A | AQY212EHAX | NFB:Panasonic_AQY212EHAX_DIP4_SMD | POPULATE | Footprint exacto EHAX SMD cerrado PR13; contacto seco aislado SELV <=48V; NO MAINS.
CHILLER | Q_CHILLER | 1 | nmos | 2N7002 | 2N7002,215 | Package_TO_SOT_SMD:SOT-23 | POPULATE | Nexperia production; driver LED PhotoMOS sin cargar GPIO.
CHILLER | R_CH_LED | 1 | resistor | 360R 1% | CRCW0402360RFKED | Resistor_SMD:R_0402_1005Metric | POPULATE | 5.0mA mínimo con Vf=1.5V y 3.3V rail.
CHILLER | R_CH_GATE | 1 | resistor | 1k 1% | CRCW04021K00FKED | Resistor_SMD:R_0402_1005Metric | POPULATE | Serie D8->gate NMOS.
CHILLER | R_CH_GATE_PD | 1 | resistor | 100k 1% | CRCW0402100KFKED | Resistor_SMD:R_0402_1005Metric | POPULATE | Fail-safe chiller contact open durante arranque.
CHILLER | J_CHILLER_CTL | 1 | connector | MSTBA 2.5/2-G-5.08 | 1757242 | Connector_Phoenix_MSTB:PhoenixContact_MSTBA_2,5_2-G-5,08_1x02_P5.08mm_Horizontal | POPULATE | Contacto seco flotante; no conectar a GND shield; orientar -Y.
DIAGNOSTIC | R_ACT_FAULT_PU | 1 | resistor | 10k 1% | CRCW040210K0FKED | Resistor_SMD:R_0402_1005Metric | POPULATE | Pull-up único para wired-OR nFAULT+FLT1 hacia D10.
DIAGNOSTIC | TP_ACT_FAULT | 1 | testpoint | ACT_FAULT_N | PCB_FEATURE | TestPoint:TestPoint_Pad_D1.0mm | PCB_FEATURE | Bring-up fault común.

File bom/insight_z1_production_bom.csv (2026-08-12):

canal | ref | qty | funcion | valor | mpn_o_familia | footprint | poblacion | nota
PH | J_PH | 1 | connector | JST XH 3p side-entry | S3B-XH-A(LF)(SN) | Connector_JST:JST_XH_S3B-XH-A_1x03_P2.50mm_Horizontal | POPULATE | Side-entry; orientar hacia -Y sobre FIELD I/O EDGE.
PH | D_PH | 1 | esd | PESD3V3U1UL | PESD3V3U1UL,315 | Diode_SMD:D_SOD-882 | POPULATE
PH | R_PH | 1 | resistor | 1k 1% | CRCW04021K00FKED | Resistor_SMD:R_0402_1005Metric | POPULATE
PH | C_PH | 1 | capacitor | 100nF 25V X7R | GRM155R71E104KE14D | Capacitor_SMD:C_0402_1005Metric | POPULATE
ORP | J_ORP | 1 | connector | JST XH 3p side-entry | S3B-XH-A(LF)(SN) | Connector_JST:JST_XH_S3B-XH-A_1x03_P2.50mm_Horizontal | POPULATE | Side-entry; orientar hacia -Y sobre FIELD I/O EDGE.
ORP | R_ORP_TOP | 1 | resistor | 10k 0.1% | Vishay TNPW0402 e3 / 10k / 0.1% | Resistor_SMD:R_0402_1005Metric | POPULATE
ORP | R_ORP_BOT | 1 | resistor | 20k 0.1% | Vishay TNPW0402 e3 / 20k / 0.1% | Resistor_SMD:R_0402_1005Metric | POPULATE
ORP | D_ORP | 1 | esd | PESD3V3U1UL | PESD3V3U1UL,315 | Diode_SMD:D_SOD-882 | POPULATE | Clamp en ORP_ADC, después del divisor 10k/20k.
ORP | C_ORP | 1 | capacitor | 100nF 25V X7R | GRM155R71E104KE14D | Capacitor_SMD:C_0402_1005Metric | POPULATE
TEMP | J_TEMP | 1 | connector | JST XH 3p side-entry | S3B-XH-A(LF)(SN) | Connector_JST:JST_XH_S3B-XH-A_1x03_P2.50mm_Horizontal | POPULATE | Side-entry; orientar hacia -Y sobre FIELD I/O EDGE.
TEMP | D_TEMP | 1 | esd | PESD3V3U1UL | PESD3V3U1UL,315 | Diode_SMD:D_SOD-882 | POPULATE
TEMP | R_TEMP_PU | 1 | resistor | 4.7k 1% | CRCW04024K70FKED | Resistor_SMD:R_0402_1005Metric | POPULATE
CO2 | U_CO2 | 1 | pressure_sensor | MPR 0-30 psi abs I2C 0x28 | MPRLS0030PA00002A | NFB:Honeywell_MPR_LongPort_12Pad | POPULATE | Sensor onboard; puerto largo para tubing. A4/CO2_ADC eliminado.
CO2 | C_CO2 | 1 | capacitor | 100nF 25V X7R | GRM155R71E104KE14D | Capacitor_SMD:C_0402_1005Metric | POPULATE
CO2 | R_CO2_SDA_PU | 1 | resistor | 10k | DNP / generic 0402 | Resistor_SMD:R_0402_1005Metric | DNP | Footprint de respaldo; DNP. Pull-ups globales se resolverán en Z2.
CO2 | R_CO2_SCL_PU | 1 | resistor | 10k | DNP / generic 0402 | Resistor_SMD:R_0402_1005Metric | DNP | Footprint de respaldo; DNP. Pull-ups globales se resolverán en Z2.
DO | J_DO | 1 | connector | JST XH 3p side-entry | S3B-XH-A(LF)(SN) | Connector_JST:JST_XH_S3B-XH-A_1x03_P2.50mm_Horizontal | POPULATE | Side-entry; orientar hacia -Y sobre FIELD I/O EDGE.
DO | D_DO | 1 | esd | PESD3V3U1UL | PESD3V3U1UL,315 | Diode_SMD:D_SOD-882 | POPULATE
DO | R_DO | 1 | resistor | 1k 1% | CRCW04021K00FKED | Resistor_SMD:R_0402_1005Metric | POPULATE
DO | C_DO | 1 | capacitor | 100nF 25V X7R | GRM155R71E104KE14D | Capacitor_SMD:C_0402_1005Metric | POPULATE

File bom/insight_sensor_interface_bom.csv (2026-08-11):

canal | logical_ref | funcion | valor_objetivo | mpn | disposicion | nota
PH | J_PH | Conector salida acondicionador | 3-pin PH2.0 compatible |  | SELECT_AT_PLACEMENT | No BNC en la PCBA NFB; BNC permanece en módulo DFRobot
PH | D_PH | Protección entrada | low-leakage ESD clamp |  | REVIEW | Seleccionar después de análisis de fuga/ruido
PH | R_PH | Serie/filtro | TBD |  | REVIEW | Congelar junto con C_PH según ancho de banda requerido
PH | C_PH | Filtro RC | TBD |  | REVIEW | Congelar corte después de prueba de ruido
PH | SYS_PH_ISO | Aislador externo opcional | DFR0504 o equivalente | DFR0504 | SYSTEM_OPTION | No es placement de la PCBA
ORP | J_ORP | Conector salida acondicionador | 3-pin PH2.0 compatible |  | SELECT_AT_PLACEMENT | Entrada desde SEN0464 ya acondicionada
ORP | D_ORP | Protección entrada | low-leakage ESD clamp |  | REVIEW | Seleccionar después de análisis de fuga/ruido
ORP | R_ORP_TOP | Divisor ADC | 10k 0.1% |  | PROVISIONAL_VALIDATED | Con R_ORP_BOT produce relación 2/3
ORP | R_ORP_BOT | Divisor ADC | 20k 0.1% |  | PROVISIONAL_VALIDATED | 4.5 V máximo -> 3.0 V al UNO Q
ORP | C_ORP | Filtro RC | TBD |  | REVIEW | Congelar corte después de prueba de ruido
ORP | SYS_ORP_ISO | Aislador externo opcional | DFR0504 o equivalente | DFR0504 | SYSTEM_OPTION | No es placement de la PCBA
TEMP | J_TEMP | Conector DS18B20 | 3-pin digital |  | SELECT_AT_PLACEMENT | Orientado Y=0 hacia -Y
TEMP | D_TEMP | Protección 1-Wire | 3.3V compatible |  | REVIEW | Seleccionar baja capacitancia
TEMP | R_TEMP_PU | Pull-up 1-Wire | 4.7k a 3.3V |  | DNP_REVIEW | Kit KIT0021 ya incluye módulo/resistencia; evitar duplicación innecesaria
CO2 | J_CO2 | Conector transductor presión | 3-pin analog |  | SELECT_AT_PLACEMENT | Sensor de producción aún por seleccionar
CO2 | D_CO2 | Protección entrada | 3.3V ADC compatible |  | REVIEW | Congelar con sensor final
CO2 | R_CO2_TOP | Divisor legado MPX5700 | 18k 0.1% |  | PROVISIONAL_LEGACY_ONLY | No congelar hasta seleccionar sensor vigente
CO2 | R_CO2_BOT | Divisor legado MPX5700 | 30k 0.1% |  | PROVISIONAL_LEGACY_ONLY | 4.813 V worst case -> 3.008 V al UNO Q
CO2 | C_CO2 | Filtro RC | TBD |  | REVIEW | Congelar con sensor final
DO | J_DO | Conector salida acondicionador | 3-pin PH2.0 compatible |  | SELECT_AT_PLACEMENT | No BNC en la PCBA NFB; BNC permanece en módulo DFRobot
DO | D_DO | Protección entrada | low-leakage ESD clamp |  | REVIEW | Seleccionar después de análisis de fuga/ruido
DO | R_DO | Serie/filtro | TBD |  | REVIEW | Congelar junto con C_DO según ancho de banda requerido
DO | C_DO | Filtro RC | TBD |  | REVIEW | Congelar corte después de prueba de ruido
DO | SYS_DO_ISO | Aislador externo opcional | DFR0504 o equivalente | DFR0504 | SYSTEM_OPTION | No es placement de la PCBA

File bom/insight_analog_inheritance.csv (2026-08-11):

canal | donor_ref | funcion | valor | mpn | disposicion | revision_requerida
PH | J2 | Conector de campo | BNC aislado | 31-221-RFX | REVIEW | PREFERIR PANEL DEL ENCLOSURE
PH | D3 | Proteccion ESD | PESD5V0S1BSF | PESD5V0S1BSF | INHERIT | VALIDAR FOOTPRINT
PH | R7 | Serie entrada | 1k 1% | CRCW04021K00FKED | INHERIT | VALIDAR RUIDO Y FILTRO
PH | C12 | Filtro RC | 100nF |  | INHERIT | VALIDAR CORTE
PH | R8 | Bias/pulldown | 10M |  | REVIEW | VALIDAR IMPEDANCIA SONDA PH
PH | U4 | Buffer analogico | MCP6002 | MCP6002-I/SN | REVIEW | VALIDAR IMPEDANCIA DE ENTRADA
PH | U5 | Driver potencia aislada | SN6501 | SN6501DBVR | REVIEW | VALIDAR FUENTE AISLADA
PH | U6 | Amplificador aislado | AMC1301 | AMC1301DWVR | REVIEW | VALIDAR RANGO Y GANANCIA
PH | T1 | Transformador aislado | 750315371 | 750315371 | REVIEW | VALIDAR CON SN6501
PH | D19 | Rectificador aislado | BAT54 | BAT54,115 | REVIEW | VALIDAR POLARIDAD
PH | D20 | Rectificador aislado | BAT54 | BAT54,115 | REVIEW | VALIDAR POLARIDAD
PH | C28 | Bulk aislado | 10uF | GRM21BR61C106KE15L | INHERIT | VALIDAR TENSION
PH | R30 | Divisor precision | 511 0.1% |  | REVIEW | VALIDAR RANGO AMC1301
PH | R31 | Divisor precision | 511 0.1% |  | REVIEW | VALIDAR RANGO AMC1301
PH | TP1 | Test point | PH_BUF |  | INHERIT | UBICAR EN Z1
ORP | J3 | Conector de campo | BNC aislado | 31-221-RFX | REVIEW | PREFERIR PANEL DEL ENCLOSURE
ORP | D4 | Proteccion ESD | PESD5V0S1BSF | PESD5V0S1BSF | INHERIT | VALIDAR FOOTPRINT
ORP | R9 | Serie entrada | 1k 1% | CRCW04021K00FKED | INHERIT | VALIDAR RUIDO Y FILTRO
ORP | C15 | Filtro RC | 100nF |  | INHERIT | VALIDAR CORTE
ORP | R10 | Bias/pulldown | 10M |  | REVIEW | VALIDAR IMPEDANCIA SONDA ORP
ORP | U7 | Buffer analogico | MCP6002 | MCP6002-I/SN | REVIEW | VALIDAR RANGO BIPOLAR
ORP | U8 | Driver potencia aislada | SN6501 | SN6501DBVR | REVIEW | VALIDAR FUENTE AISLADA
ORP | U9 | Amplificador aislado | AMC1301 | AMC1301DWVR | REVIEW | VALIDAR RANGO Y GANANCIA
ORP | T2 | Transformador aislado | 750315371 | 750315371 | REVIEW | VALIDAR CON SN6501
ORP | D21 | Rectificador aislado | BAT54 | BAT54,115 | REVIEW | VALIDAR POLARIDAD
ORP | D22 | Rectificador aislado | BAT54 | BAT54,115 | REVIEW | VALIDAR POLARIDAD
ORP | C29 | Bulk aislado | 10uF | GRM21BR61C106KE15L | INHERIT | VALIDAR TENSION
ORP | R32 | Divisor precision | 4.02k 0.1% |  | REVIEW | VALIDAR RANGO AMC1301
ORP | R33 | Divisor precision | 1.00k 0.1% |  | REVIEW | VALIDAR RANGO AMC1301
ORP | TP2 | Test point | ORP_BUF |  | INHERIT | UBICAR EN Z1
TEMP | J6 | Conector de campo | JST-XH 2-pin |  | REVIEW | ORIENTAR A -Y
TEMP | D7 | Proteccion ESD | PESD3V3S1BSF | PESD3V3S1BSF | INHERIT | VALIDAR FOOTPRINT
TEMP | R15 | Serie entrada | 1k 1% | CRCW04021K00FKED | INHERIT | VALIDAR TOPOLOGIA NTC
TEMP | C22 | Filtro RC | 100nF |  | INHERIT | VALIDAR CORTE
TEMP | R16 | Bias/pulldown | 10M |  | REVIEW | VALIDAR DIVISOR NTC FINAL
CO2 | J4 | Conector de campo | JST-XH 3-pin |  | REVIEW | ORIENTAR A -Y
CO2 | D5 | Proteccion ESD | PESD5V0S1BSF | PESD5V0S1BSF | INHERIT | VALIDAR FOOTPRINT
CO2 | R11 | Serie entrada | 1k 1% | CRCW04021K00FKED | INHERIT | VALIDAR RANGO TRANSDUCTOR
CO2 | C18 | Filtro RC | 100nF |  | INHERIT | VALIDAR CORTE
CO2 | R12 | Bias/pulldown | 10M |  | REVIEW | VALIDAR RANGO TRANSDUCTOR
CO2 | U10 | Buffer analogico | MCP6002 | MCP6002-I/SN | REVIEW | VALIDAR ESCALAMIENTO ADC
DO | J5 | Conector de campo | BNC aislado | 31-221-RFX | REVIEW | PREFERIR PANEL DEL ENCLOSURE
DO | D6 | Proteccion ESD | PESD5V0S1BSF | PESD5V0S1BSF | INHERIT | VALIDAR FOOTPRINT
DO | R13 | Serie entrada | 1k 1% | CRCW04021K00FKED | INHERIT | VALIDAR SENAL SONDA DO
DO | C19 | Filtro RC | 100nF |  | INHERIT | VALIDAR CORTE
DO | R14 | Bias/pulldown | 10M |  | REVIEW | VALIDAR TIPO DE SONDA DO
DO | U11 | Buffer analogico | MCP6002 | MCP6002-I/SN | REVIEW | VALIDAR TIPO DE SONDA DO
DO | U12 | Driver potencia aislada | SN6501 | SN6501DBVR | REVIEW | VALIDAR FUENTE AISLADA
DO | U13 | Amplificador aislado | AMC1301 | AMC1301DWVR | REVIEW | VALIDAR RANGO Y GANANCIA
DO | T3 | Transformador aislado | 750315371 | 750315371 | REVIEW | VALIDAR CON SN6501
DO | D23 | Rectificador aislado | BAT54 | BAT54,115 | REVIEW | VALIDAR POLARIDAD
DO | D24 | Rectificador aislado | BAT54 | BAT54,115 | REVIEW | VALIDAR POLARIDAD
DO | C30 | Bulk aislado | 10uF | GRM21BR61C106KE15L | INHERIT | VALIDAR TENSION

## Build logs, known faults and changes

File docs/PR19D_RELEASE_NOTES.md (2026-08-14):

# PR19D — cierre ECO de potencia HMI

## Resultado

PR19D introduce una sola net de producción: `5V_HMI`, creada para separar la alimentación de la HMI Nextion del `5V_RAIL` sensible de la NFB PCBA v2.

## Arquitectura

`12V sistema → Littelfuse 0FHM0001ZXJ + 0997002.WXN 2 A → RECOM R-78K5.0-2.0L → 5V_HMI`.

La pantalla `NX8048P050-011C-Y` y el BOX Speaker consumen desde el subensamble externo. En la PCBA `5V_HMI` solo conecta `J_HMI.1`, `U_HMI_LVL.7` y `C_HMI_B.1`.

## Evidencia de routing

- lote: PR19D, ALL_OR_NOTHING 1/1;
- delta: 7 segmentos + 2 vías;
- acumulado: 924 segmentos + 121 vías;
- nets de producción vigentes: 60;
- nets ruteadas: 49/60;
- `In1.Cu`: 0 señales;
- zones: 0;
- DRC KiCad 10.0.5: 0 errores;
- warnings: 255, exactamente los históricos de silk/texto;
- unconnected: 151;
- ERC root: 0 violaciones.

## Escape VSSOP

`U_HMI_LVL.7` usa 0.20 mm por ≤1.20 mm únicamente en el fan-out inmediato del VSSOP. El clearance contractual permanece ≥0.20 mm y la distribución de `5V_HMI` retorna a 0.40 mm.

## Invariantes preservados

- placement congelado;
- outline 242.34 × 68.58 mm congelado;
- routing UART HMI previo sin cambio;
- ningún cobre de PR20A/PR20B adelantado;
- `5V_RAIL` no se une a `5V_HMI`;
- PR20A conserva sus 10 nets históricas.

## First article pendiente

El ECO queda cerrado en diseño, pero release de producto exige medir corriente/inrush, temperatura del RECOM, comportamiento del fusible 2 A, mating del arnés y EMC del conjunto HMI final.

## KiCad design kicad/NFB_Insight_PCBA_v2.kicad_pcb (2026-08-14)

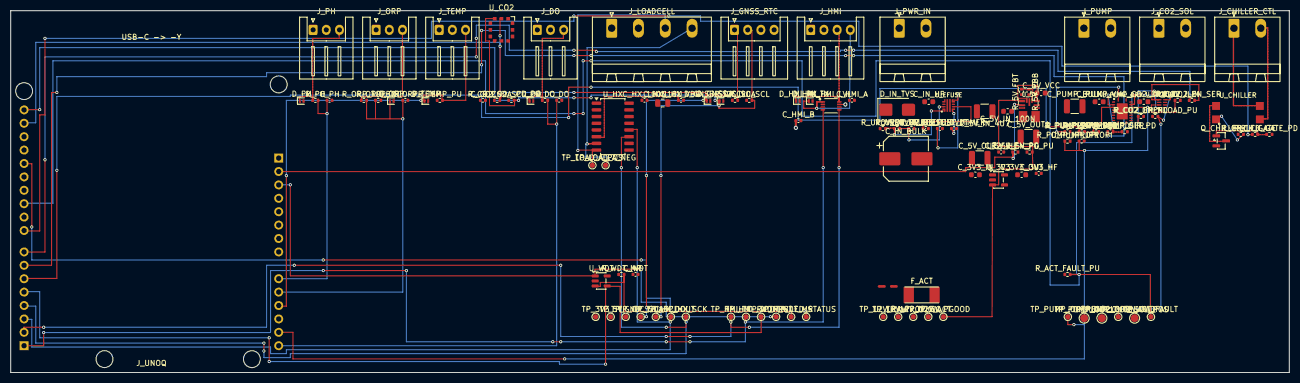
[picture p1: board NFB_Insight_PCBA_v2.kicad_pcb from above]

Board: 4 copper layers, 242.3 x 68.6 mm, 120 parts (0 on the bottom side), 60 nets.

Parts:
C_3V3_HF, C_5V_HF: 100nF 25V X7R; C_0402_1005Metric
C_3V3_IN, C_3V3_OUT, C_5V_VCC: 1uF 25V X7R; C_0603_1608Metric
C_5V_IN_4U7: 4.7uF 50V X7R; C_1210_3225Metric
C_5V_IN_100N: 100nF 50V X7R; C_0603_1608Metric
C_5V_OUT1, C_5V_OUT2: 22uF 16V X7R; C_1210_3225Metric
C_CO2: 100nF 25V X7R; C_0402_1005Metric
C_CO2_DRV: 100nF 50V X7R; C_0603_1608Metric
C_DO: 100nF 25V X7R; C_0402_1005Metric
C_EFUSE_DVDT: 3.3nF 50V X7R; C_0402_1005Metric
C_EFUSE_ITIMER: 2.2nF 50V X7R; C_0402_1005Metric
C_HMI_A: 100nF 25V X7R; C_0402_1005Metric
C_HMI_B: 100nF 25V X7R; C_0402_1005Metric
C_HX_10U: 10uF 10V X5R; C_0805_2012Metric
C_HX_100N: 100nF 25V X7R; C_0402_1005Metric
C_HX_VBG: 100nF 25V X7R; C_0402_1005Metric
C_IN_BULK: 100uF 25V; CP_Elec_8x6.2
C_IN_HF: 100nF 50V X7R; C_0603_1608Metric
C_ORP: 100nF 25V X7R; C_0402_1005Metric
C_PH: 100nF 25V X7R; C_0402_1005Metric
C_PUMP_BULK: 22uF 25V X7R; C_1210_3225Metric
C_PUMP_IPROPI: 100nF; C_0402_1005Metric
C_PUMP_VM: 100nF 50V X7R; C_0603_1608Metric
C_WDT: 100nF 25V X7R; C_0402_1005Metric
D_DO: PESD3V3U1UL; D_SOD-882
D_GNSS_SCL: PESD3V3U1UL; D_SOD-882
D_GNSS_SDA: PESD3V3U1UL; D_SOD-882
D_HMI_RX: PESD5V0U1UL; D_SOD-882
D_HMI_TX: PESD5V0U1UL; D_SOD-882
D_IN_TVS: SMBJ15A 600W 15V uni; D_SMB
D_ORP: PESD3V3U1UL; D_SOD-882
D_PH: PESD3V3U1UL; D_SOD-882
D_TEMP: PESD3V3U1UL; D_SOD-882
F_ACT: 1.5A 125V Slo-Blo Nano2; Littelfuse_0454_NANO2
J_CHILLER_CTL: MSTBA 2,5/2-G-5.08; PhoenixContact_MSTBA_2,5_2-G-5,08_1x02_P5.08mm_Horizontal
J_CO2_SOL: MSTBA 2,5/2-G-5,08; PhoenixContact_MSTBA_2,5_2-G-5,08_1x02_P5.08mm_Horizontal
J_DO: JST XH 3p side-entry; JST_XH_S3B-XH-A_1x03_P2.50mm_Horizontal
J_GNSS_RTC: JST XH 4p side-entry; JST_XH_S4B-XH-A_1x04_P2.50mm_Horizontal
J_HMI: JST XH 4p side-entry; JST_XH_S4B-XH-A_1x04_P2.50mm_Horizontal
J_LOADCELL: MSTBA 2,5/4-G-5,08; PhoenixContact_MSTBA_2,5_4-G-5,08_1x04_P5.08mm_Horizontal
J_ORP: JST XH 3p side-entry; JST_XH_S3B-XH-A_1x03_P2.50mm_Horizontal
J_PH: JST XH 3p side-entry; JST_XH_S3B-XH-A_1x03_P2.50mm_Horizontal
J_PUMP: MSTBA 2,5/2-G-5,08; PhoenixContact_MSTBA_2,5_2-G-5,08_1x02_P5.08mm_Horizontal
J_PWR_IN: MSTBA 2,5/2-G-5,08; PhoenixContact_MSTBA_2,5_2-G-5,08_1x02_P5.08mm_Horizontal
J_TEMP: JST XH 3p side-entry; JST_XH_S3B-XH-A_1x03_P2.50mm_Horizontal
J_UNOQ: Arduino_UNO_Q_Carrier_Rotated
NT_HOST: NET_TIE_2; NetTie-2_SMD_Pad0.5mm
NT_LOGIC: NET_TIE_2; NetTie-2_SMD_Pad0.5mm
Q_CHILLER: 2N7002; SOT-23
R_5V_EN_PD: 100k 1%; R_0402_1005Metric
R_5V_FBB: 10k 1%; R_0402_1005Metric
R_5V_FBT: 40.2k 1%; R_0402_1005Metric
R_5V_PG_PU: 47k 1%; R_0402_1005Metric
R_ACT_FAULT_PU: 10k; R_0402_1005Metric
R_CH_GATE: 1k; R_0402_1005Metric
R_CH_GATE_PD: 100k; R_0402_1005Metric
R_CH_LED: 360R 1%; R_0402_1005Metric
R_CO2_EN_PD: 100k; R_0402_1005Metric
R_CO2_EN_SER: 100R; R_0402_1005Metric
R_CO2_ILIM: 27k 1%; R_0402_1005Metric
R_CO2_OPENLOAD_PU, R_CO2_SCL_PU, R_CO2_SDA_PU: 10k; R_0402_1005Metric
R_DO: 1k 1%; R_0402_1005Metric
R_EFUSE_ILIM: 750R 1%; R_0402_1005Metric
R_I2C_SCL, R_I2C_SDA: 4.7k 1%; R_0402_1005Metric
R_ORP_BOT: 20k 0.1%; R_0402_1005Metric
R_ORP_TOP: 10k 0.1%; R_0402_1005Metric
R_PH: 1k 1%; R_0402_1005Metric
R_PUMP_DIR_PD: 100k; R_0402_1005Metric
R_PUMP_DIR_SER: 100R; R_0402_1005Metric
R_PUMP_IPROPI: 1.5k 1%; R_0402_1005Metric
R_PUMP_PWM_PD: 100k; R_0402_1005Metric
R_PUMP_PWM_SER: 100R; R_0402_1005Metric
R_PUMP_SR: 22k; R_0402_1005Metric
R_TEMP_PU: 4.7k 1%; R_0402_1005Metric
R_UVOV_R1: 470k 1%; R_0402_1005Metric
R_UVOV_R2: 11k 1%; R_0402_1005Metric
R_UVOV_R3: 47k 1%; R_0402_1005Metric
R_WDT_MR: 10k 1%; R_0402_1005Metric
TP_3V3, TP_5V, TP_5V_PGOOD, TP_12V_ACT, TP_12V_LOGIC, TP_12V_PROT, TP_12V_RAW: PCB test point; TestPoint_Pad_D1.0mm
TP_ACT_FAULT: TESTPOINT; TestPoint_Pad_D1.0mm
TP_CO2_OPENLOAD: TESTPOINT; TestPoint_Pad_D1.0mm
TP_CO2_SOL_POS: TESTPOINT; TestPoint_Pad_D1.5mm
TP_GND: PCB test point; TestPoint_Pad_D1.0mm
TP_HMI_RX: PCB test point; TestPoint_Pad_D1.0mm
TP_HMI_TX: PCB test point; TestPoint_Pad_D1.0mm
TP_HX_DOUT: PCB test point; TestPoint_Pad_D1.0mm
TP_HX_SCK: PCB test point; TestPoint_Pad_D1.0mm
TP_I2C_SCL, TP_I2C_SDA: PCB test point; TestPoint_Pad_D1.0mm
TP_LED_STATUS: PCB test point; TestPoint_Pad_D1.0mm
TP_LOAD_A_NEG: PCB test point; TestPoint_Pad_D1.0mm
TP_LOAD_A_POS: PCB test point; TestPoint_Pad_D1.0mm
TP_NRST: PCB test point; TestPoint_Pad_D1.0mm
TP_PUMP_CURRENT: TESTPOINT; TestPoint_Pad_D1.0mm
TP_PUMP_OUT1, TP_PUMP_OUT2: TESTPOINT; TestPoint_Pad_D1.5mm
TP_WDI: PCB test point; TestPoint_Pad_D1.0mm
TP_WDT_MR: PCB test point; TestPoint_Pad_D1.0mm
U_3V3: TLV75533 3.3V/500mA; SOT-23-5
U_5V: TPSM33625 5V/2.5A; TI_RDN0011A_TPSM33625
U_CHILLER: PhotoMOS GE DIP4 1 Form A; Panasonic_AQY212EHAX_DIP4_SMD
U_CO2: MPR 0-30 psi abs I2C 0x28; Honeywell_MPR_LongPort_12Pad
U_CO2_DRV: TPS1HC120C-Q1; TI_DYC0008A_TPS1HC120
U_EFUSE: TPS259470A; TI_RPW0010A_TPS259470A
U_HMI_LVL: TXU0202; TI_DCU0008A_TXU0202
U_HX: HX711 24-bit; SOP-16_4.4x10.4mm_P1.27mm
U_PUMP_DRV: DRV8242H-Q1; TI_RHL0020B_DRV8242
U_WDT: TPS3823-30 1.6s; SOT-23-5

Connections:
3V3_RAIL: C_3V3_HF.1, C_3V3_OUT.1, C_CO2.1, C_HMI_A.1, C_HX_10U.1, C_HX_100N.1, C_WDT.1, J_GNSS_RTC.4, J_LOADCELL.1, J_TEMP.1, R_ACT_FAULT_PU.1, R_CH_LED.1, R_CO2_OPENLOAD_PU.1, R_CO2_SCL_PU.1, R_CO2_SDA_PU.1, R_I2C_SCL.1, R_I2C_SDA.1, R_TEMP_PU.1, R_WDT_MR.1, TP_3V3.1, U_3V3.5, U_CO2.12, U_HMI_LVL.3, U_HMI_LVL.6, U_HX.1, U_HX.3, U_HX.16, U_PUMP_DRV.16, U_WDT.5
5V_FB: R_5V_FBB.1, R_5V_FBT.2, U_5V.9
5V_HMI: C_HMI_B.1, J_HMI.1, U_HMI_LVL.7
5V_PGOOD: R_5V_PG_PU.2, TP_5V_PGOOD.1, U_3V3.3, U_5V.1
5V_RAIL: C_3V3_IN.1, C_5V_HF.1, C_5V_OUT1.1, C_5V_OUT2.1, J_DO.1, J_ORP.1, J_PH.1, R_5V_FBT.1, R_5V_PG_PU.1, TP_5V.1, U_3V3.1, U_5V.4
5V_VCC: C_5V_VCC.1, U_5V.8, U_5V.11
12V_ACT: C_CO2_DRV.1, C_PUMP_BULK.1, C_PUMP_VM.1, F_ACT.2, TP_12V_ACT.1, U_CO2_DRV.8, U_PUMP_DRV.6, U_PUMP_DRV.15
12V_HOST_VIN: J_UNOQ.8, NT_HOST.2
12V_IN_RAW: C_IN_HF.1, D_IN_TVS.1, J_PWR_IN.1, R_UVOV_R1.1, TP_12V_RAW.1, U_EFUSE.5
12V_LOGIC: C_5V_IN_4U7.1, C_5V_IN_100N.1, NT_LOGIC.2, TP_12V_LOGIC.1, U_5V.3
12V_PROTECTED: C_IN_BULK.1, F_ACT.1, NT_HOST.1, NT_LOGIC.1, TP_12V_PROT.1, U_EFUSE.6
ACT_FAULT_N: J_UNOQ.25, R_ACT_FAULT_PU.2, TP_ACT_FAULT.1, U_CO2_DRV.1, U_PUMP_DRV.18
CHILLER_CONTACT_A: J_CHILLER_CTL.1, U_CHILLER.3
CHILLER_CONTACT_B: J_CHILLER_CTL.2, U_CHILLER.4
CHILLER_CTL: J_UNOQ.23, R_CH_GATE.1
CHILLER_GATE: Q_CHILLER.1, R_CH_GATE.2, R_CH_GATE_PD.1
CHILLER_LED_A: R_CH_LED.2, U_CHILLER.1
CHILLER_LED_K: Q_CHILLER.3, U_CHILLER.2
CO2_EN_DRV: R_CO2_EN_PD.1, R_CO2_EN_SER.2, U_CO2_DRV.4
CO2_ILIM: R_CO2_ILIM.1, U_CO2_DRV.2
CO2_OPENLOAD_N: R_CO2_OPENLOAD_PU.2, TP_CO2_OPENLOAD.1, U_CO2_DRV.5
CO2_SOL_CTL: J_UNOQ.22, R_CO2_EN_SER.1
CO2_SOL_POS: J_CO2_SOL.1, TP_CO2_SOL_POS.1, U_CO2_DRV.7
DO_ADC: C_DO.1, J_UNOQ.14, R_DO.2
DO_FIELD_SIG: D_DO.1, J_DO.3, R_DO.1
EFUSE_DVDT: C_EFUSE_DVDT.1, U_EFUSE.7
EFUSE_EN_UVLO: R_UVOV_R1.2, R_UVOV_R2.1, U_EFUSE.1
EFUSE_ILM: R_EFUSE_ILIM.1, U_EFUSE.9
EFUSE_ITIMER: C_EFUSE_ITIMER.1, U_EFUSE.10
EFUSE_OVLO: R_UVOV_R2.2, R_UVOV_R3.1, U_EFUSE.2
GND: C_3V3_HF.2, C_3V3_IN.2, C_3V3_OUT.2, C_5V_HF.2, C_5V_IN_4U7.2, C_5V_IN_100N.2, C_5V_OUT1.2, C_5V_OUT2.2, C_5V_VCC.2, C_CO2.2, C_CO2_DRV.2, C_DO.2, C_EFUSE_DVDT.2, C_EFUSE_ITIMER.2, C_HMI_A.2, C_HMI_B.2, C_HX_10U.2, C_HX_100N.2, C_HX_VBG.2, C_IN_BULK.2, C_IN_HF.2, C_ORP.2, C_PH.2, C_PUMP_BULK.2, C_PUMP_IPROPI.2, C_PUMP_VM.2, C_WDT.2, D_DO.2, D_GNSS_SCL.2, D_GNSS_SDA.2, D_HMI_RX.2, D_HMI_TX.2, D_IN_TVS.2, D_ORP.2, D_PH.2, D_TEMP.2, J_CO2_SOL.2, J_DO.2, J_GNSS_RTC.3, J_HMI.2, J_LOADCELL.2, J_ORP.2, J_PH.2, J_PWR_IN.2, J_TEMP.2, J_UNOQ.6, J_UNOQ.7, J_UNOQ.29, Q_CHILLER.2, R_5V_EN_PD.2, R_5V_FBB.2, R_CH_GATE_PD.2, R_CO2_EN_PD.2, R_CO2_ILIM.2, R_EFUSE_ILIM.2, R_ORP_BOT.2, R_PUMP_DIR_PD.2, R_PUMP_IPROPI.2, R_PUMP_PWM_PD.2, R_PUMP_SR.2, R_UVOV_R3.2, TP_GND.1, U_3V3.2, U_5V.10, U_CO2.10, U_CO2_DRV.3, U_CO2_DRV.6, U_EFUSE.8, U_HMI_LVL.2, U_HX.4, U_HX.5, U_HX.14, U_HX.15, U_PUMP_DRV.2, U_PUMP_DRV.5, U_PUMP_DRV.9, U_PUMP_DRV.10, U_PUMP_DRV.11, U_PUMP_DRV.12, U_PUMP_DRV.19, U_PUMP_DRV.20, U_PUMP_DRV.21, U_WDT.2
HMI_FIELD_RX: D_HMI_RX.1, J_HMI.3, U_HMI_LVL.8
HMI_FIELD_TX: D_HMI_TX.1, J_HMI.4, U_HMI_LVL.1
HMI_RX: J_UNOQ.15, TP_HMI_RX.1, U_HMI_LVL.4
HMI_TX: J_UNOQ.16, TP_HMI_TX.1, U_HMI_LVL.5
HX711_DOUT: J_UNOQ.17, TP_HX_DOUT.1, U_HX.12
HX711_SCK: J_UNOQ.18, TP_HX_SCK.1, U_HX.11
HX_VBG: C_HX_VBG.1, U_HX.6
I2C_SCL: D_GNSS_SCL.1, J_GNSS_RTC.2, J_UNOQ.32, R_CO2_SCL_PU.2, R_I2C_SCL.2, TP_I2C_SCL.1, U_CO2.3
I2C_SDA: D_GNSS_SDA.1, J_GNSS_RTC.1, J_UNOQ.31, R_CO2_SDA_PU.2, R_I2C_SDA.2, TP_I2C_SDA.1, U_CO2.2
LED_STATUS: J_UNOQ.28, TP_LED_STATUS.1
LOAD_A_NEG: J_LOADCELL.4, TP_LOAD_A_NEG.1, U_HX.7
LOAD_A_POS: J_LOADCELL.3, TP_LOAD_A_POS.1, U_HX.8
MCU_NRST: J_UNOQ.3, TP_NRST.1, U_WDT.1
MCU_WDI: J_UNOQ.19, TP_WDI.1, U_WDT.4
ORP_ADC: C_ORP.1, D_ORP.1, J_UNOQ.10, R_ORP_BOT.1, R_ORP_TOP.2
ORP_FIELD_SIG: J_ORP.3, R_ORP_TOP.1
PH_ADC: C_PH.1, J_UNOQ.9, R_PH.2
PH_FIELD_SIG: D_PH.1, J_PH.3, R_PH.1
PUMP_CURRENT_ADC: C_PUMP_IPROPI.1, J_UNOQ.13, R_PUMP_IPROPI.1, TP_PUMP_CURRENT.1, U_PUMP_DRV.17
PUMP_DIR: J_UNOQ.21, R_PUMP_DIR_SER.1
PUMP_DIR_DRV: R_PUMP_DIR_PD.1, R_PUMP_DIR_SER.2, U_PUMP_DRV.3
PUMP_OUT1: J_PUMP.1, TP_PUMP_OUT1.1, U_PUMP_DRV.7, U_PUMP_DRV.8
PUMP_OUT2: J_PUMP.2, TP_PUMP_OUT2.1, U_PUMP_DRV.13, U_PUMP_DRV.14
PUMP_PWM: J_UNOQ.20, R_PUMP_PWM_SER.1
PUMP_PWM_DRV: R_PUMP_PWM_PD.1, R_PUMP_PWM_SER.2, U_PUMP_DRV.4
PUMP_SR_CFG: R_PUMP_SR.1, U_PUMP_DRV.1
TEMP_1WIRE: D_TEMP.1, J_TEMP.3, J_UNOQ.11, R_TEMP_PU.2
UNO_IOREF_3V3: J_UNOQ.2, R_5V_EN_PD.1, U_5V.2
WDT_MR_N: R_WDT_MR.2, TP_WDT_MR.1, U_WDT.3

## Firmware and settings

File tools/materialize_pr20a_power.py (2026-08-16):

#!/usr/bin/env python3
"""Materializa candidato PR20A sobre PR19D sin tocar placement, outline, zones ni GND.

Arquitectura de capas:
- In2.Cu: troncales de distribución 5V/3V3/12V protegida/host/logic y salidas Z4.
- F.Cu: entrada local, ramas locales y 12V_ACT dirty en Z3/Z4.
- In1.Cu: reservado; no se usa.
Los neck-downs existen solo como escapes cortos de pads SMD más estrechos que
el ancho de distribución; no reducen el clearance ni la sección de las troncales.
"""
from __future__ import annotations
import json
from pathlib import Path
import pcbnew

ROOT=Path(__file__).resolve().parents[1]
PCB=ROOT/'kicad'/'NFB_Insight_PCBA_v2.kicad_pcb'
OUT=ROOT/'hardware'/'pr20a_power_routing_manifest.json'
TARGET=["12V_IN_RAW","12V_PROTECTED","12V_HOST_VIN","12V_LOGIC","12V_ACT","5V_RAIL","3V3_RAIL","PUMP_OUT1","PUMP_OUT2","CO2_SOL_POS"]
BASE_SEG=924; BASE_VIA=121

def iu(x): return pcbnew.FromMM(float(x))
def V(x,y): return pcbnew.VECTOR2I(iu(x),iu(y))
def fail(m): raise SystemExit('ERROR: '+m)

def netmap(board):
    out={}
    for fp in board.GetFootprints():
        for p in fp.Pads():
            if p.GetNetname() and p.GetNetname() not in out:
                out[p.GetNetname()]=p.GetNet()
    return out

def main():
    b=pcbnew.LoadBoard(str(PCB)); nets=netmap(b)
    seg0=sum(not isinstance(t,pcbnew.PCB_VIA) for t in b.GetTracks()); via0=sum(isinstance(t,pcbnew.PCB_VIA) for t in b.GetTracks())
    if (seg0,via0)!=(BASE_SEG,BASE_VIA): fail(f'baseline PR19D inesperado {(seg0,via0)}')
    if len(b.Zones())!=0: fail('PR20A requiere zones=0 antes de PR20B')
    touched={t.GetNetname() for t in b.GetTracks()}
    early=sorted(set(TARGET)&touched)
    if early: fail(f'PR20A debe iniciar sin cobre propio: {early}')
    if 'GND' in touched: fail('GND fue adelantado antes de PR20B')
    missing=[n for n in TARGET if n not in nets]
    if missing: fail(f'nets PR20A ausentes del PCB: {missing}')

    new_segments=[]; new_vias=[]
    def S(net,layer,a,z,w,role='distribution'):
        t=pcbnew.PCB_TRACK(b); t.SetNet(nets[net]); t.SetLayer(layer); t.SetWidth(iu(w)); t.SetStart(V(*a)); t.SetEnd(V(*z)); b.Add(t)
        new_segments.append({'net':net,'layer':b.GetLayerName(layer),'start_mm':[float(a[0]),float(a[1])],'end_mm':[float(z[0]),float(z[1])],'width_mm':float(w),'role':role})
    def VIA(net,p,d,drill,role='distribution'):
        v=pcbnew.PCB_VIA(b); v.SetNet(nets[net]); v.SetPosition(V(*p)); v.SetWidth(iu(d)); v.SetDrill(iu(drill)); b.Add(v)
        new_vias.append({'net':net,'at_mm':[float(p[0]),float(p[1])],'diameter_mm':float(d),'drill_mm':float(drill),'role':role})

    # --- 12V_IN_RAW: spine 2 mm, stubs diagnósticos/sense pad-compatible.
    n='12V_IN_RAW'
    S(n,pcbnew.F_Cu,(168.405,3.325),(168.405,11.5),2.0)
    S(n,pcbnew.F_Cu,(168.405,11.5),(175.0,11.5),2.0)
    S(n,pcbnew.F_Cu,(175.0,11.5),(175.0,17.975),2.0)
    S(n,pcbnew.F_Cu,(175.0,17.975),(177.525,17.975),0.30,'smd_escape')
    S(n,pcbnew.F_Cu,(168.405,11.5),(168.405,18.775),2.0)
    S(n,pcbnew.F_Cu,(168.405,18.775),(165.865,18.775),2.0)
    S(n,pcbnew.F_Cu,(173.22,17.255),(173.22,15.0),0.50,'passive_stub')
    S(n,pcbnew.F_Cu,(173.22,15.0),(168.405,15.0),0.50,'passive_stub')
    S(n,pcbnew.F_Cu,(165.865,18.775),(164.0,18.775),0.40,'sense_stub')
    S(n,pcbnew.F_Cu,(164.0,18.775),(164.0,22.345),0.40,'sense_stub')
    S(n,pcbnew.F_Cu,(164.0,22.345),(164.785,22.345),0.40,'sense_stub')
    S(n,pcbnew.F_Cu,(164.0,22.345),(164.0,64.0),0.40,'test_stub')
    S(n,pcbnew.F_Cu,(164.0,64.0),(165.365,64.0),0.40,'test_stub')
    S(n,pcbnew.F_Cu,(165.365,64.0),(165.365,58.025),0.40,'test_stub')

    # --- 12V_PROTECTED: transición robusta a In2 y estrella Z3.
    n='12V_PROTECTED'
    S(n,pcbnew.F_Cu,(178.025,17.975),(180.0,17.975),0.30,'smd_escape')
    S(n,pcbnew.F_Cu,(180.0,17.975),(182.8,17.975),2.0)
    VIA(n,(181.4,17.3),1.2,0.6,'current_array')
    VIA(n,(181.4,18.7),1.2,0.6,'current_array')
    VIA(n,(182.8,17.975),1.2,0.6,'current_array')
    S(n,pcbnew.In2_Cu,(181.4,17.3),(182.8,17.975),2.0)
    S(n,pcbnew.In2_Cu,(181.4,18.7),(182.8,17.975),2.0)
    S(n,pcbnew.In2_Cu,(182.8,17.975),(182.8,43.0),2.0)
    S(n,pcbnew.In2_Cu,(182.8,43.0),(168.0,43.0),2.0)
    # bulk: subir a F desde la estrella para no cruzar troncales 5V/3V3 en In2
    VIA(n,(168.0,43.0),1.2,0.6)
    S(n,pcbnew.F_Cu,(168.0,43.0),(168.0,35.0),2.0)
    S(n,pcbnew.F_Cu,(168.0,35.0),(166.615,28.065),2.0)
    # net-ties: escape angosto solo junto al pad; vía ya fuera del par de pads
    S(n,pcbnew.F_Cu,(164.59,52.25),(164.2,50.0),0.40,'nettie_escape')
    VIA(n,(164.2,50.0),1.2,0.6)
    S(n,pcbnew.In2_Cu,(164.2,50.0),(164.2,45.0),2.0)
    S(n,pcbnew.In2_Cu,(164.2,45.0),(168.0,43.0),2.0)
    S(n,pcbnew.F_Cu,(166.89,52.25),(166.0,49.0),0.40,'nettie_escape')
    VIA(n,(166.0,49.0),1.2,0.6)
    S(n,pcbnew.In2_Cu,(166.0,49.0),(166.0,45.0),2.0)
    S(n,pcbnew.In2_Cu,(166.0,45.0),(168.0,43.0),2.0)
    S(n,pcbnew.F_Cu,(170.213,53.875),(170.213,49.0),2.0)
    VIA(n,(170.213,49.0),1.2,0.6)
    S(n,pcbnew.In2_Cu,(170.213,49.0),(170.213,43.0),2.0)
    S(n,pcbnew.F_Cu,(170.213,53.875),(170.213,56.0),0.50,'test_stub')
    S(n,pcbnew.F_Cu,(170.213,56.0),(168.215,56.0),0.50,'test_stub')
    S(n,pcbnew.F_Cu,(168.215,56.0),(168.215,58.025),0.50,'test_stub')

    # --- 12V_HOST_VIN: long-haul In2 desde la estrella hacia J_UNOQ.
    n='12V_HOST_VIN'
    S(n,pcbnew.F_Cu,(165.59,52.25),(165.59,54.5),0.50,'nettie_escape')
    VIA(n,(165.59,54.5),0.9,0.45)
    S(n,pcbnew.In2_Cu,(165.59,54.5),(165.59,51.5),1.0)
    S(n,pcbnew.In2_Cu,(165.59,51.5),(50.8,51.5),1.0)
    S(n,pcbnew.In2_Cu,(50.8,51.5),(50.8,45.72),1.0)

    # --- 12V_LOGIC: corredor In2 por borde derecho de Z3, lejos de troncales bajas.
    n='12V_LOGIC'
    S(n,pcbnew.F_Cu,(167.89,52.25),(168.8,55.0),0.50,'nettie_escape')
    VIA(n,(168.8,55.0),0.9,0.45)
    S(n,pcbnew.In2_Cu,(168.8,55.0),(197.8,55.0),1.0)
    S(n,pcbnew.In2_Cu,(197.8,55.0),(197.8,20.0),1.0)
    S(n,pcbnew.In2_Cu,(197.8,20.0),(184.5,20.0),1.0)
    VIA(n,(184.5,20.0),0.9,0.45)
    S(n,pcbnew.F_Cu,(184.5,20.0),(186.075,19.075),1.0)
    S(n,pcbnew.F_Cu,(186.075,19.075),(190.0,18.425),1.0)
    S(n,pcbnew.F_Cu,(190.0,18.425),(191.675,18.425),0.30,'smd_escape')
    S(n,pcbnew.F_Cu,(189.725,19.075),(189.725,18.75),0.50,'passive_stub')
    S(n,pcbnew.F_Cu,(189.725,18.75),(190.0,18.425),0.50,'passive_stub')
    S(n,pcbnew.F_Cu,(167.89,52.25),(171.065,55.5),0.50,'test_stub')
    S(n,pcbnew.F_Cu,(171.065,55.5),(171.065,58.025),0.50,'test_stub')

    # --- 5V_RAIL: isla buck en F, troncal horizontal In2 a Z1, TP por F.
    n='5V_RAIL'
    S(n,pcbnew.F_Cu,(191.875,20.075),(191.42,23.875),0.75)
    S(n,pcbnew.F_Cu,(191.42,23.875),(187.245,25.5),0.75)
    S(n,pcbnew.F_Cu,(187.245,25.5),(187.245,26.785),0.50,'passive_stub')
    S(n,pcbnew.F_Cu,(187.245,26.785),(182.19,27.925),0.75)
    S(n,pcbnew.F_Cu,(182.19,27.925),(179.5,28.0),0.75)
    VIA(n,(179.5,28.0),0.8,0.4)
    S(n,pcbnew.In2_Cu,(179.5,28.0),(57.315,28.0),0.75)
    S(n,pcbnew.In2_Cu,(57.315,28.0),(57.315,3.635),0.75)
    S(n,pcbnew.In2_Cu,(69.265,28.0),(69.265,3.635),0.75)
    S(n,pcbnew.In2_Cu,(99.815,28.0),(99.815,3.635),0.75)
    # TP: salir a F antes de cruzar la futura troncal 3V3
    VIA(n,(126.0,28.0),0.8,0.4,'test_branch')
    S(n,pcbnew.F_Cu,(126.0,28.0),(126.0,55.0),0.75,'test_branch')
    S(n,pcbnew.F_Cu,(126.0,55.0),(113.715,55.0),0.75,'test_branch')
    S(n,pcbnew.F_Cu,(113.715,55.0),(113.715,58.025),0.75,'test_branch')
    # feedback/pull-up y entrada LDO como stubs locales del rail
    S(n,pcbnew.F_Cu,(191.6,15.9),(191.6,18.7),0.40,'passive_stub')
    S(n,pcbnew.F_Cu,(191.6,18.7),(191.875,20.075),0.40,'passive_stub')
    S(n,pcbnew.F_Cu,(192.615,26.795),(191.42,25.5),0.40,'passive_stub')
    S(n,pcbnew.F_Cu,(182.19,27.925),(182.07,31.105),0.75)
    S(n,pcbnew.F_Cu,(182.07,31.105),(186.088,31.125),0.75)

    # --- 3V3_RAIL: fuente local F, troncal In2 solo hacia la izquierda; bus Z4 en F.
    n='3V3_RAIL'
    S(n,pcbnew.F_Cu,(188.363,31.125),(190.83,31.105),0.40)
    S(n,pcbnew.F_Cu,(190.83,31.105),(194.365,30.835),0.40)
    S(n,pcbnew.F_Cu,(194.365,30.835),(194.365,36.0),0.40)
    S(n,pcbnew.F_Cu,(194.365,36.0),(179.0,36.0),0.40)
    VIA(n,(179.0,36.0),0.7,0.35)
    S(n,pcbnew.In2_Cu,(179.0,36.0),(80.0,36.0),0.40)
    # Z1 TEMP
    VIA(n,(82.0,36.0),0.7,0.35)
    S(n,pcbnew.F_Cu,(82.0,36.0),(82.0,16.995),0.40)
    S(n,pcbnew.F_Cu,(82.0,16.995),(80.835,16.995),0.40)
    S(n,pcbnew.F_Cu,(82.0,16.995),(81.215,3.635),0.40)
    # Z1 CO2/pull-ups
    VIA(n,(96.5,36.0),0.7,0.35)
    S(n,pcbnew.F_Cu,(96.5,36.0),(96.5,18.5),0.40)
    S(n,pcbnew.F_Cu,(96.5,18.5),(88.5,18.5),0.40)
    for x,y in [(89.02,16.985),(91.68,16.995),(94.39,16.995)]: S(n,pcbnew.F_Cu,(x,18.5),(x,y),0.40,'passive_stub')
    S(n,pcbnew.F_Cu,(96.5,18.5),(96.5,5.0),0.40)
    S(n,pcbnew.F_Cu,(96.5,5.0),(95.115,2.355),0.30,'smd_escape')
    # Z2 TP + watchdog
    VIA(n,(109.5,36.0),0.7,0.35)
    S(n,pcbnew.F_Cu,(109.5,36.0),(109.5,54.0),0.40)
    S(n,pcbnew.F_Cu,(109.5,54.0),(110.865,58.025),0.40)
    S(n,pcbnew.F_Cu,(109.5,54.0),(118.5,54.0),0.40)
    for x,y in [(113.052,50.275),(115.235,49.995),(117.955,49.985)]: S(n,pcbnew.F_Cu,(x,54.0),(x,y),0.40,'passive_stub')
    # Z2 HX711 + loadcell
    VIA(n,(125.0,36.0),0.7,0.35)
    S(n,pcbnew.F_Cu,(125.0,36.0),(125.0,23.0),0.40)
    S(n,pcbnew.F_Cu,(125.0,23.0),(109.5,23.0),0.40)
    S(n,pcbnew.F_Cu,(111.028,23.0),(111.028,17.53),0.40)
    S(n,pcbnew.F_Cu,(111.028,20.07),(111.028,17.53),0.40)
    for x,y in [(117.203,17.53),(119.645,16.985),(122.635,17.505)]: S(n,pcbnew.F_Cu,(x,23.0),(x,y),0.40,'passive_stub')
    S(n,pcbnew.F_Cu,(109.5,23.0),(109.5,8.0),0.40)
    S(n,pcbnew.F_Cu,(109.5,8.0),(113.905,3.325),0.40)
    # Z2 I2C/GNSS
    VIA(n,(145.5,36.0),0.7,0.35)
    S(n,pcbnew.F_Cu,(145.5,36.0),(145.5,19.0),0.40)
    S(n,pcbnew.F_Cu,(145.5,19.0),(135.5,19.0),0.40)
    for x,y in [(136.775,16.995),(139.485,16.995)]: S(n,pcbnew.F_Cu,(x,19.0),(x,y),0.40,'passive_stub')
    S(n,pcbnew.F_Cu,(145.5,19.0),(144.685,3.635),0.40)
    # Z2 HMI lado 3V3
    VIA(n,(160.5,36.0),0.7,0.35)
    S(n,pcbnew.F_Cu,(160.5,36.0),(160.5,20.5),0.40)
    S(n,pcbnew.F_Cu,(160.5,20.5),(153.935,20.5),0.40)
    for x,y in [(153.935,18.275),(157.035,18.275),(158.965,16.985)]: S(n,pcbnew.F_Cu,(x,20.5),(x,y),0.30 if '15' else 0.40,'smd_escape' if x in (153.935,157.035) else 'passive_stub')
    # Z4 bus: continuar en F desde la fuente, separado de 12V_ACT dirty (y=63/40)
    S(n,pcbnew.F_Cu,(194.365,36.0),(234.0,36.0),0.40)
    S(n,pcbnew.F_Cu,(199.785,36.0),(199.785,49.995),0.40)
    # pump pin16: fanout por la derecha evitando vías existentes
    S(n,pcbnew.F_Cu,(211.0,36.0),(211.0,28.0),0.40)
    S(n,pcbnew.F_Cu,(211.0,28.0),(215.5,28.0),0.40)
    S(n,pcbnew.F_Cu,(215.5,28.0),(215.5,23.0),0.40)
    S(n,pcbnew.F_Cu,(215.5,23.0),(214.5,20.0),0.40)
    S(n,pcbnew.F_Cu,(214.5,20.0),(213.6,18.825),0.40)
    S(n,pcbnew.F_Cu,(213.6,18.825),(212.325,18.825),0.20,'smd_escape')
    # CO2 open-load pull-up pad1 desde la izquierda
    S(n,pcbnew.F_Cu,(215.0,36.0),(215.0,20.045),0.40)
    S(n,pcbnew.F_Cu,(215.0,20.045),(216.415,20.045),0.40)
    # chiller LED resistor pad1
    S(n,pcbnew.F_Cu,(232.635,36.0),(232.635,29.0),0.40)
    S(n,pcbnew.F_Cu,(232.635,29.0),(232.635,23.445),0.40)

    # --- 12V_ACT: dirty trunk F, solo Z3/Z4; top corridor preserva sensible PUMP_CURRENT_ADC.
    n='12V_ACT'
    S(n,pcbnew.F_Cu,(175.118,53.875),(175.118,63.0),1.0)
    S(n,pcbnew.F_Cu,(173.915,58.025),(175.118,58.025),0.50,'test_stub')
    S(n,pcbnew.F_Cu,(175.118,63.0),(198.8,63.0),1.0)
    S(n,pcbnew.F_Cu,(198.8,63.0),(198.8,40.0),1.0)
    S(n,pcbnew.F_Cu,(198.8,40.0),(222.0,40.0),1.0)
    # pump left power pin6 + caps
    S(n,pcbnew.F_Cu,(207.5,40.0),(207.5,19.325),1.0)
    S(n,pcbnew.F_Cu,(207.5,19.325),(209.025,19.325),0.20,'smd_escape')
    S(n,pcbnew.F_Cu,(207.5,27.0),(205.52,17.255),1.0)
    S(n,pcbnew.F_Cu,(205.52,17.255),(200.19,18.125),1.0)
    # pump pin15 por fanout corto a la derecha
    S(n,pcbnew.F_Cu,(213.5,40.0),(213.5,19.325),1.0)
    S(n,pcbnew.F_Cu,(213.5,19.325),(212.325,19.325),0.20,'smd_escape')
    # CO2 pin8 por la derecha
    S(n,pcbnew.F_Cu,(220.5,40.0),(220.5,19.5),1.0)
    S(n,pcbnew.F_Cu,(220.5,19.5),(220.5,18.375),0.30,'smd_escape')
    S(n,pcbnew.F_Cu,(220.5,18.375),(218.82,18.375),0.20,'smd_escape')
    # bypass CO2 desde rama segura a la izquierda de la vía sensible
    S(n,pcbnew.F_Cu,(213.5,19.325),(213.0,19.325),0.40,'passive_stub')
    S(n,pcbnew.F_Cu,(213.0,19.325),(213.0,17.255),0.40,'passive_stub')
    S(n,pcbnew.F_Cu,(213.0,17.255),(213.99,17.255),0.40,'passive_stub')

    # --- PUMP_OUT1: salida dirty por In2; F solo fanout/TP.
    n='PUMP_OUT1'
    S(n,pcbnew.F_Cu,(209.025,19.825),(207.5,19.825),0.20,'smd_escape')
    S(n,pcbnew.F_Cu,(209.025,20.325),(207.5,20.325),0.20,'smd_escape')
    S(n,pcbnew.F_Cu,(207.5,19.825),(207.5,20.325),0.20,'smd_escape')
    S(n,pcbnew.F_Cu,(207.5,20.075),(205.5,20.075),0.75)
    VIA(n,(205.5,20.075),0.9,0.45)
    S(n,pcbnew.In2_Cu,(205.5,20.075),(202.0,20.075),0.75)
    S(n,pcbnew.In2_Cu,(202.0,8.0),(202.0,56.0),0.75)
    S(n,pcbnew.In2_Cu,(202.0,8.0),(203.405,3.325),0.75)
    S(n,pcbnew.In2_Cu,(202.0,56.0),(204.0,56.0),0.75)
    VIA(n,(204.0,56.0),0.9,0.45)
    S(n,pcbnew.F_Cu,(204.0,56.0),(203.465,58.275),0.75)

    # --- PUMP_OUT2
    n='PUMP_OUT2'
    S(n,pcbnew.F_Cu,(212.325,19.825),(214.0,19.825),0.20,'smd_escape')
    S(n,pcbnew.F_Cu,(212.325,20.325),(214.0,20.325),0.20,'smd_escape')
    S(n,pcbnew.F_Cu,(214.0,19.825),(214.0,20.325),0.20,'smd_escape')
    S(n,pcbnew.F_Cu,(214.0,20.075),(216.5,20.075),0.75)
    VIA(n,(216.5,20.075),0.9,0.45)
    S(n,pcbnew.In2_Cu,(216.5,20.075),(206.5,20.075),0.75)
    S(n,pcbnew.In2_Cu,(206.5,8.0),(206.5,56.0),0.75)
    S(n,pcbnew.In2_Cu,(206.5,8.0),(208.485,3.325),0.75)
    VIA(n,(206.5,56.0),0.9,0.45)
    S(n,pcbnew.F_Cu,(206.5,56.0),(206.815,58.275),0.75)

    # --- CO2_SOL_POS
    n='CO2_SOL_POS'
    S(n,pcbnew.F_Cu,(218.82,17.875),(219.5,17.875),0.20,'smd_escape')
    S(n,pcbnew.F_Cu,(219.5,17.875),(219.5,16.8),0.20,'smd_escape')
    S(n,pcbnew.F_Cu,(219.5,16.8),(221.0,16.8),0.75)
    VIA(n,(221.0,16.8),0.9,0.45)
    S(n,pcbnew.In2_Cu,(221.0,8.0),(221.0,56.0),0.75)
    S(n,pcbnew.In2_Cu,(221.0,8.0),(217.625,3.325),0.75)
    S(n,pcbnew.In2_Cu,(221.0,56.0),(214.5,56.0),0.75)
    VIA(n,(214.5,56.0),0.9,0.45)
    S(n,pcbnew.F_Cu,(214.5,56.0),(213.015,58.275),0.75)

    manifest={
      'schema_version':1,'status':'CANDIDATE_POWER_ROUTING_PR20A','target_nets':TARGET,
      'baseline':{'segments':BASE_SEG,'vias':BASE_VIA,'zones':0},
      'new_segment_count':len(new_segments),'new_via_count':len(new_vias),
      'new_segments':new_segments,'new_vias':new_vias,
      'policies':{'in1_signal_tracks':0,'zones_added':0,'gnd_copper_added':0,'future_batch_copper':0,'placement_change':0,'outline_change':0},
      'distribution_width_mm':{'12V_IN_RAW':2.0,'12V_PROTECTED':2.0,'12V_HOST_VIN':1.0,'12V_LOGIC':1.0,'12V_ACT':1.0,'5V_RAIL':0.75,'3V3_RAIL':0.40,'PUMP_OUT1':0.75,'PUMP_OUT2':0.75,'CO2_SOL_POS':0.75},
      'escape_policy':'Pad-compatible local neck-down only; trunks retain frozen PR18 widths; no clearance relaxation.'
    }
    pcbnew.SaveBoard(str(PCB),b); OUT.write_text(json.dumps(manifest,indent=2,ensure_ascii=False)+'\n',encoding='utf-8')
    print(f'PR20A candidate: +{len(new_segments)} segments +{len(new_vias)} vias => {BASE_SEG+len(new_segments)}/{BASE_VIA+len(new_vias)}')

if __name__=='__main__': main()

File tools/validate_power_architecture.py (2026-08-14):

#!/usr/bin/env python3
"""Valida arquitectura PR9/PR10 bajo contrato UNO Q y routing incremental hasta PR19D."""
from __future__ import annotations
import json, math, re
from pathlib import Path
ROOT=Path(__file__).resolve().parents[1]
POWER=ROOT/"hardware"/"power_architecture_contract.json"; PIN=ROOT/"hardware"/"insight_pin_contract.json"; Z1=ROOT/"hardware"/"z1_production_netlist.json"; Z2=ROOT/"hardware"/"z2_production_netlist.json"; Z4=ROOT/"hardware"/"z4_production_netlist.json"; PCB=ROOT/"kicad"/"NFB_Insight_PCBA_v2.kicad_pcb"; README=ROOT/"README.md"; ROADMAP=ROOT/"docs"/"ROADMAP.md"; SOURCES=ROOT/"docs"/"SOURCE_OF_TRUTH.md"; POWERDOC=ROOT/"docs"/"POWER_ARCHITECTURE.md"; PLACEMENT=ROOT/"hardware"/"placement_manifest.json"; ROUTING_BATCHES=ROOT/"hardware"/"routing_batches_contract.json"; PR19A_MANIFEST=ROOT/"hardware"/"pr19a_local_routing_manifest.json"; PR19D_MANIFEST=ROOT/"hardware"/"pr19d_hmi_power_routing_manifest.json"
ARDUINO_SNAPSHOT="196feda03787005572a059f030677b8a1de9bcd2"
def fail(m): raise SystemExit("ERROR: "+m)
def main():
    for x in (POWER,PIN,Z1,Z2,Z4,PCB,README,ROADMAP,SOURCES,POWERDOC):
        if not x.exists(): fail(f"falta {x.relative_to(ROOT)}")
    c=json.loads(POWER.read_text(encoding="utf-8")); p=json.loads(PIN.read_text(encoding="utf-8")); z1=json.loads(Z1.read_text(encoding="utf-8")); z2=json.loads(Z2.read_text(encoding="utf-8")); z4=json.loads(Z4.read_text(encoding="utf-8"))
    if c.get("schema_version")!=2 or c.get("status")!="POWER_ARCHITECTURE_BASELINE_PR9" or c.get("production_status")!="POWER_PRODUCTION_BASELINE_PR10": fail("baseline potencia PR9/10 cambió")
    if c.get("design_object")!="SHIELD_CARRIER_FOR_ARDUINO_UNO_Q": fail("objeto diseño incorrecto")
    sh=c["source_hierarchy"]; prim=" ".join(sh["uno_q_primary"]).lower(); snap=sh.get("arduino_docs_content_snapshot",{})
    if "github.com/arduino" not in prim or "arduino/docs-content" not in prim or snap.get("commit")!=ARDUINO_SNAPSHOT: fail("fuente primaria Arduino PR9 cambió")
    required_files={"content/hardware/02.uno/boards/uno-q/datasheet/datasheet.md","content/hardware/02.uno/boards/uno-q/tutorials/03.power-specification/content.md","content/hardware/02.uno/carriers/uno-breakout-carrier/datasheet/datasheet.md"}
    if set(snap.get("files",[]))!=required_files: fail("snapshot Arduino incompleto")
    official=set(c["host_power"]["official_supported_inputs"])
    if not {"USB-C 5 V / up to 3 A","VIN 7-24 V","regulated 5 V through JANALOG 5 V pin / up to 3 A"}<=official: fail("métodos alimentación UNO Q incompletos")
    if c["host_power"]["preferred_method_for_nfb"]!="VIN_7_TO_24V": fail("NFB no usa VIN")
    lo,hi=map(float,c["input"]["allowed_v"])
    if not (lo<=12<=hi and hi<23): fail("ventana 12V incompatible")
    ef=c["input_protection"]["efuse"]
    if ef["mpn"]!="TPS259470ARPWR" or ef["vin_range_v"]!=[2.7,23.0] or float(ef["current_capability_a"])<5.5 or not 0.5<=float(ef["target_current_limit_a"])<=5.5: fail("eFuse baseline incorrecto")
    if c["input_protection"]["tvs"]["family"]!="SMBJ15A": fail("TVS baseline incorrecto")
    split={b["net"]:b for b in c["star_split"]["branches"]}
    if set(split)!={"12V_HOST_VIN","12V_LOGIC","12V_ACT"}: fail("split estrella incorrecto")
    if c["star_split"]["chiller_power_on_pcba"] is not False or c["actuator_policy"]["chiller"]!="external power; control only": fail("chiller power reapareció")
    u5=c["shield_5v"]["regulator"]; u3=c["shield_3v3"]["regulator"]
    if c["shield_5v"]["host_5v_tied"] or u5["mpn"]!="TPSM33625RDNR" or float(u5["design_continuous_limit_a"])>1.5: fail("5V baseline incorrecto")
    if c["shield_5v"]["enable"]["source"]!="UNO_IOREF_3V3": fail("5V no secuenciado por IOREF")
    if c["shield_3v3"]["host_3v3_tied"] or u3["mpn"]!="TLV75533PDBVR" or float(u3["design_continuous_limit_a"])>0.25: fail("3V3 baseline incorrecto")
    # PR19D puede añadir potencia HMI externa, pero no cambia los tres bloques de diseño de la PCBA principal.
    b=c["power_budget"]; total=float(b["host_branch_w_design"])+float(b["shield_5v_w_design"])+float(b["actuator_12v_w_design"])
    if not math.isclose(total,float(b["total_w_design"]),abs_tol=1e-9) or float(b["recommended_supply_w"])<total*1.25: fail("budget potencia sin margen")
    if c.get("external_hmi_power"):
        eh=c["external_hmi_power"]
        if eh.get("converter")!="RECOM R-78K5.0-2.0L 5V/2A" or eh.get("output_net")!="5V_HMI" or eh.get("main_pcba_high_current_path") is not False: fail("ECO HMI externo inconsistente")
        if c["shield_5v"].get("hmi_integration",{}).get("status")!="CLOSED_EXTERNAL_DEDICATED_5V_HMI": fail("5V_RAIL aún reclama HMI")
    if p.get("schema_version")!=6 or p.get("power_architecture_source_of_truth")!="hardware/power_architecture_contract.json": fail("pin contract no enlaza potencia")
    pins={int(x["pad"]):x for x in p["pins"]}
    if (pins[2]["net"],pins[2]["status"])!=("UNO_IOREF_3V3","ACTIVE_CONTROL_OUTPUT") or (pins[8]["net"],pins[8]["status"])!=("12V_HOST_VIN","ACTIVE_POWER_INPUT"): fail("frontera IOREF/VIN incorrecta")
    if pins[4]["net"] is not None or pins[5]["net"] is not None or pins[5]["status"]!="NC_HOST_5V_SUPPORTED_INPUT": fail("frontera rails host incorrecta")
    for nz,name in ((z1,"Z1"),(z2,"Z2"),(z4,"Z4")):
        nets={x["name"]:set(x["nodes"]) for x in nz["nets"]}
        if "J_UNOQ.4" in nets.get("3V3_RAIL",set()) or "J_UNOQ.5" in nets.get("5V_RAIL",set()): fail(f"{name} back-feed host")
    n2={x["name"]:set(x["nodes"]) for x in z2["nets"]}
    if "5V_HMI" in n2:
        if n2["5V_HMI"]!={"J_HMI.1","U_HMI_LVL.7","C_HMI_B.1"}: fail("5V_HMI Z2 tiene endpoints inesperados")
        if n2["5V_HMI"] & n2.get("5V_RAIL",set()): fail("5V_HMI puenteado a 5V_RAIL")
    n4={x["name"]:set(x["nodes"]) for x in z4["nets"]}
    if "12V_ACT" not in n4 or "U_PUMP_DRV.6" not in n4["12V_ACT"] or "U_CO2_DRV.8" not in n4["12V_ACT"]: fail("Z4 no consume rama 12V_ACT")
    if any(x in n4["12V_ACT"] for x in ("U_CHILLER.3","U_CHILLER.4")): fail("chiller conectado a potencia PCBA")
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

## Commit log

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2026-08-11 feat(kicad): crear board mecánica base 68.58 mm
    [NFB_Insight_PCBA_v2.kicad_pcb]
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2026-08-11 esquemático: congelar contrato eléctrico Insight
    * docs: definir contrato eléctrico Insight para PR3
    * feat: añadir contrato de pines Insight legible por máquina
    * feat: crear root schematic limpio para contrato Insight
    * test: validar contrato Insight contra UNO Q
    * ci: validar contrato esquemático Insight y ERC
    * docs: actualizar Fase 2 con baseline contractual PR3
    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
    [NFB_Insight_PCBA_v2.kicad_sch]
2026-08-11 analógico: congelar arquitectura y BOM de Insight (#4)
    Migra de forma controlada la arquitectura analógica útil del Q-Shield: cinco canales Insight, aislamiento pH/ORP/DO, BOM trazable, exclusión A3/HUM y gates automáticos de validación. La materializaci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
    [analog_insight.kicad_sch, insight_analog_inheritance.csv]
2026-08-11 sensores: corregir interfaces reales de Insight (#5)
    Corrige el baseline eléctrico de sensores contra documentación oficial: señales acondicionadas para pH/ORP/DO, A2/D16 como DS18B20 1-Wire, escalamiento seguro de entradas analógicas y MPX5700AP bloqueado para reemplazo antes de fabricación.
    [NFB_Insight_PCBA_v2.kicad_sch, insight_sensor_interface_bom.csv]
2026-08-12 sensores: congelar netlist de producción Z1 (#6)
    Congela Z1 para NFB Insight V2: Honeywell MPRLS0030PA00002A por I2C 0x28, A4 DNP, interfaces pH/ORP/TEMP/DO, conectores JST XH, ESD, filtros, BOM/netlist machine-readable y gates de validación. Place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
    [NFB_Insight_PCBA_v2.kicad_sch, insight_z1_production_bom.csv]
2026-08-12 digital: congelar Z2 de bajo ruido para Insight (#7)
    Congela Z2 para Insight: I2C global 4.7k, DFR1103 GNSS+RTC 0x66, HX711 D2/D3, HMI con TXU0202, watchdog TPS3823-30, test points, BOM/netlist y gates KiCad. Mantiene placement y routing fuera de alcan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
    [insight_z2_production_bom.csv, z2_digital_contract.kicad_sch]
2026-08-12 compliance: congelar gate UE del shield UNO Q (#8)
    Define la frontera de cumplimiento del NFB Insight PCBA v2 como shield/carrier del Arduino UNO Q, preserva RF del host, añade matriz EMC/RoHS3/WEEE/RED/REACH/CE, gate CI, roadmap y README sincronizad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
    [EU_COMPLIANCE_MATRIX.csv]
2026-08-12 potencia: congelar arquitectura Fase 3 y frontera UNO Q (#9)
    Congela el power tree del shield sobre 12V→VIN UNO Q, separa rails locales 5V/3V3, selecciona eFuse/buck/LDO, formaliza GitHub oficial Arduino como fuente primaria y mantiene Z1/Z2/compliance coheren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
    [NFB_Insight_PCBA_v2.kicad_sch, z2_digital_contract.kicad_sch]
2026-08-12 potencia: materializar esquemático y BOM de producción PR10
    Congela el baseline discreto de potencia, netlist/BOM/netclasses, cálculos del eFuse/buck/LDO, ERC y documentación; conserva placement/routing bloqueados hasta auditoría de footprints críticos.
    [insight_power_production_bom.csv, power.kicad_sch]
2026-08-12 integración: auditar footprints críticos y congelar Z1+Z2+Z3 (#11)
    Cierra el footprint Honeywell MPR contra fuente primaria, formaliza gates de footprints TI críticos y congela la integración eléctrica Z1+Z2+Z3 sin habilitar placement ni routing.
    [integration_contract.kicad_sch]
2026-08-12 actuadores: congelar Z4 protegido y diagnosticable para Insight (#12)
    Sustituye etapas legacy por DRV8242H-Q1, TPS1HC120C-Q1 y PhotoMOS AQY212EHAX; añade telemetría de bomba en A4, diagnóstico común D10, SELV/no-mains para chiller y gates Z4 con 10/10 checks verdes.
    [NFB_Insight_PCBA_v2.kicad_sch, insight_z4_production_bom.csv, integration_contract.kicad_sch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]
2026-08-12 footprints: cerrar encapsulados críticos antes de placement (#13)
    Cierra RPW0010A, RDN0011A, RHL0020B, DYC0008A y AQY212EHAX contra fuentes primarias; incorpora Spark solo como cross-check, corrige discrepancias de geometría/package, actualiza BOM/netlists/README y deja 9/9 gates verdes sin placement ni routing.
    [insight_power_production_bom.csv, insight_z4_production_bom.csv, power.kicad_sch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]
2026-08-12 eda: integrar jerarquía raíz Z0-Z4 de Insight (#14)
    Materializa la jerarquía inter-zona Z0-Z4 sin placement/routing. Congela una deuda ERC transitoria y reproducible de 125 label_dangling causada exclusivamente por la ausencia deliberada de símbolos i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
    [NFB_Insight_PCBA_v2.kicad_sch, uno_q_interface.kicad_sch, z1_interface.kicad_sch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]
2026-08-12 eda: materializar hierarchy de producción y cerrar ERC en cero (#15)
    Materializa Z0–Z4 de forma determinista desde JSON/BOM, registra NFB_GEN, cierra seis links físicos verificados, elimina la deuda ERC de PR #14 y congela ERC=0/0 antes de placement. Mantiene placemen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
    [insight_power_production_bom.csv, insight_z2_production_bom.csv, insight_z4_production_bom.csv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]
2026-08-12 placement: congelar readiness físico antes de XY (#16)
    Revalida UNO Q contra arduino/docs-content, congela reglas RF/EMC/field-I/O sin inventar un antenna keepout numérico, cierra J_LOADCELL con Phoenix 1757268, sincroniza J_UNOQ con su librería y deja E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
    [insight_z2_production_bom.csv, z2_interface.kicad_sch]
2026-08-12 placement: materializar layout PR17 de NFB Insight
    Congela el placement físico de NFB Insight PCBA v2 en 242.34 × 68.58 mm, con Z0=53.34 mm, Z1=55.50 mm, Z2=54.50 mm, Z3=35.00 mm y Z4=44.00 mm. Materializa 120 footprints totales y 59 nets, manteniendo routing, vías y zonas de cobre en cero. Corrige Honeywell MPR contra Figure 10 del datasheet y conserva el land pattern TI del TPSM33625 con clearance interno local de 0.125 mm. DRC PR17: 0 errores y 0 tipos físicos prohibidos; deuda acotada de 246 warnings silk/text y 250 unconnected por routing=0. Reproducibilidad KiCad validada semánticamente tolerando UUIDs regenerados.
    [NFB_Insight_PCBA_v2.kicad_pcb]
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2026-08-13 placement: corregir micro-isla TPSM33625 antes de routing
    ECO local Z3 guiado por TI TPSM33625 §8.5.1. Mueve únicamente C_5V_IN_4U7, C_5V_IN_100N, C_5V_VCC, R_5V_FBT y R_5V_FBB; preserva U_5V, outline, zonas, netlist y routing. DRC físico=0; 114 refs restan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
    [NFB_Insight_PCBA_v2.kicad_pcb]
2026-08-13 placement: acercar testpoints load-cell al HX711 antes de routing
    ECO localizado Z2 previo a routing.
    - mueve únicamente TP_LOAD_A_POS y TP_LOAD_A_NEG cerca de U_HX;
    - conserva el ECO PR22 Z3 del TPSM33625;
    - valida 2 refs movidas / 117 intactas;
    - mantiene outline, zonas, netlist, footprints y routing sin cambios;
    - DRC físico: 0 errores, sin shorts/clearance/courtyard;
    - deuda placement-only: 255 warnings silk/text acotados, 4 menos que PR22, y 250 unconnected;
    - hace composicional el gate histórico PR22: valida su delta local contra PR17 y reproduce la cadena ECO vigente antes de manifest/PCB/DRC.
    PR24 no agrega routing. El siguiente checkpoint reinicia PR19A limpio con política 28/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
    [NFB_Insight_PCBA_v2.kicad_pcb]
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2026-08-13 routing: cerrar PR19A 28/28 nets locales
    Cierra el primer lote físico de routing PR19A sobre el baseline post-PR24/PR25.
    - 28/28 nets locales con cobre.
    - 31/31 nets futuras intactas.
    - 523 segmentos y 24 vías.
    - In1.Cu sin signal routing; 0 copper zones.
    - KiCad 10.0.5 DRC: 0 errors.
    - 255 warnings conocidos exclusivamente de serigrafía/texto.
    - 204 unconnected restantes, ninguno perteneciente a PR19A.
    - 5V_PGOOD simplificado de 143 a 12 segmentos.
    - WDT_MR_N simplificado de 100 a 10 segmentos.
    - Gates históricos adaptados de forma composicional sin relajar contratos.
    - README.md actualizado con el checkpoint y PR19B como siguiente lote.
    [NFB_Insight_PCBA_v2.kicad_pcb]
2026-08-13 docs: corregir referencia PR19A a PR #28
    Corrige dos referencias de numeración en README.md para identificar correctamente el checkpoint de producción PR19A como PR #28. Sin cambios de PCB, routing, contratos ni tooling.
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2026-08-13 routing: persistir PR19B 4/4 con DRC 0
    [NFB_Insight_PCBA_v2.kicad_pcb]
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2026-08-14 routing: corregir 20 errores DRC localizados de PR19C
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2026-08-14 routing: persistir checkpoint PR19C 16/16 DRC=0
    [NFB_Insight_PCBA_v2.kicad_pcb]
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2026-08-14 power: cerrar ECO HMI con 5V_HMI dedicado y PR19D
    [NFB_Insight_PCBA_v2.kicad_pcb, insight_hmi_system_bom.csv, insight_z2_production_bom.csv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]
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
